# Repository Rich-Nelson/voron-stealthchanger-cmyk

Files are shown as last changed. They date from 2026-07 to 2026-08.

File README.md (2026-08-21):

# Voron Stealthchanger CMYK

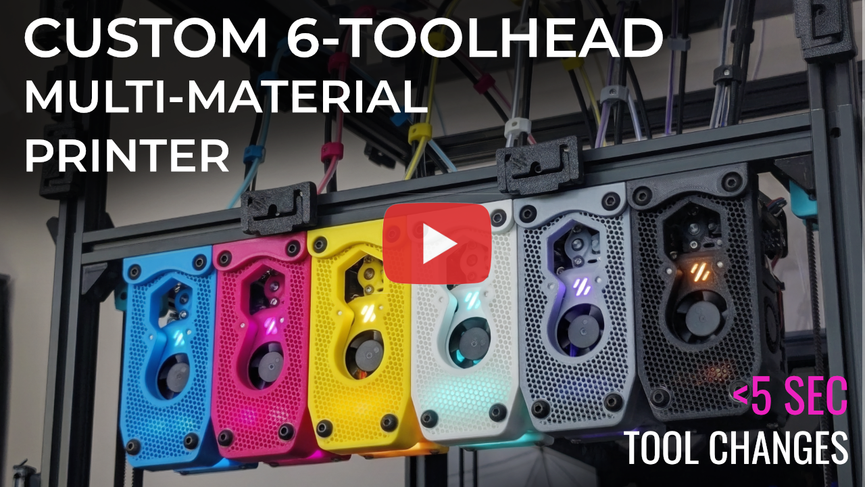
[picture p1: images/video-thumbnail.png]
Voron Stealthchanger CMYK - Watch on YouTube (https://www.youtube.com/watch?v=wOfLphvfhsM)


This repo contains all of the custom files for my 6-toolhead multi-material 3D printer, which is based on a [Voron 2.4](https://github.com/VoronDesign/Voron-2) using the [StealthChanger](https://github.com/DraftShift/StealthChanger) toolchanging system, and the [Tapchanger docking mechanism](https://github.com/viesturz/tapchanger). The build prioritizes performance, maintainability, auto calibration, and aesthetics. The CMYK in the name reffered to my printer color scheme, it's a nod to the subtractive primary colors used by 2D printers and to the capabilities of a multi tool 3D printer especially with slicer advancement like full spectrum color.

Each tool head uses a Dragon Burner toolhead with a Sharkpa Mini Extruder and TZ 2.0 V6 hotend, chosen for their combination of print quality and cost-effectiveness. The entire build is made from 3D printed parts and off-the-shelf hardware.

This repo documents all of the custom and modified components.

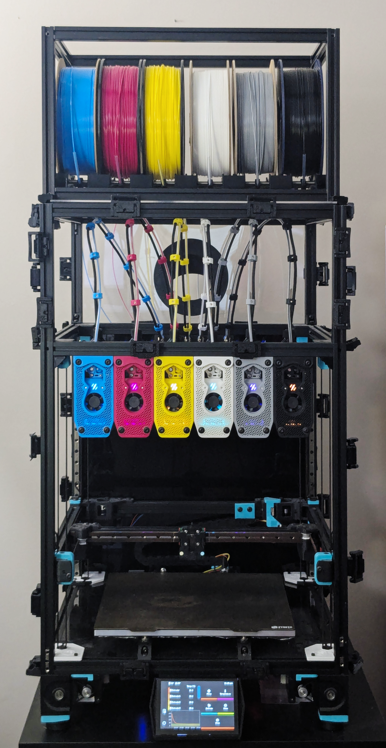
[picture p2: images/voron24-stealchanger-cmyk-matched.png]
Voron Stealthchanger CMYK


## Table of Contents

- [Filaments Used in This Build](#filaments-used-in-this-build)
- [Components](#components)
  - [Toolhead Dock](dock/)
  - [Umbilical Backplate](umbilical-backplate/)
  - [Umbilical Bracket](umbilical-bracket/)
  - [Spool Holder](spool-holder/)
  - [Dragon Burner Toolhead](dragon-burner-toolhead/)
  - [Nozzle Brush Mount](nozzle-brush-mount/)
  - [CAN Distribution Board Mount](can-distribution-board-mount/)
  - [Toolchange Tuning](toolchange-tuning/)
- [Cost Estimate Guide](COST-ESTIMATE.md)
## Filaments used in this build

Finding the right color filaments was quite difficult, since online photos do not always match the actual color. So here are the exact filaments I used so you dont't have to keep buying rolls of filament until you find the right Cyan and Magenta...

| Color | Filament | Source |
|---|---|---|
| Cyan | Polymaker ASA Pop Blue | [Amazon](https://amzn.to/4gcIvKo)
| Magenta | MatterHackers Magenta ABS | [MatterHackers](https://www.matterhackers.com/store/3d-printer-filament/magenta-abs-filament-1.75mm)
| Yellow | MatterHackers Yellow ABS | [MatterHackers](https://www.matterhackers.com/store/l/175mm-abs-filament-yellow-1-kg/sk/M-1NX-QXFR)
| White | Polymaker White ABS | [Amazon (ABS)](https://amzn.to/4cA1c8l) / [Amazon (ASA)](https://amzn.to/45FyLlC)
| Gray | Polymaker Gray ASA | [Amazon (ABS)](https://amzn.to/4xRpfb5) / [Amazon (ASA)](https://amzn.to/3ULpFkU) 
| Black | Polymaker Black ABS | [Amazon (ABS)](https://amzn.to/4zvPRzW) / [Amazon (ASA)](https://amzn.to/4xUeXqN)

---

## Components

<table>
<tr>
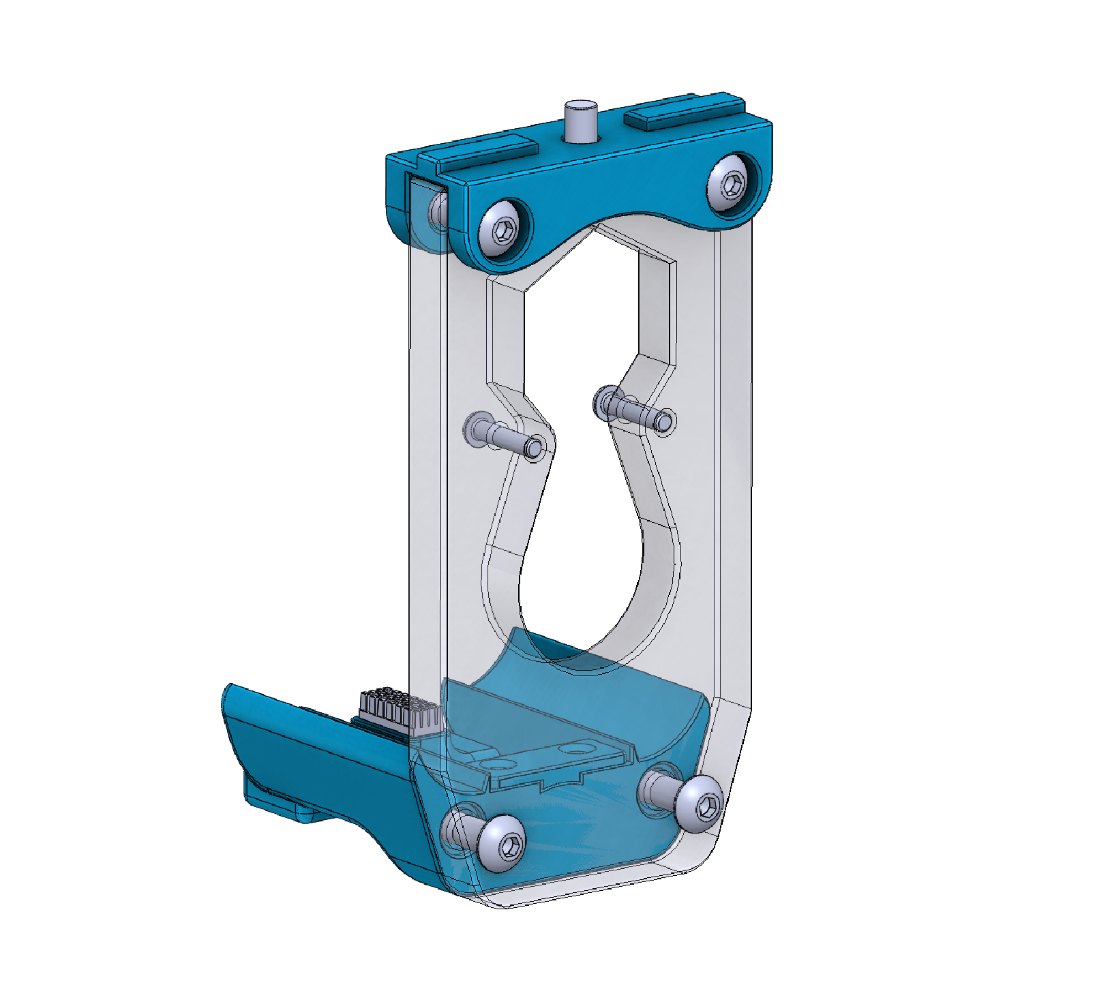
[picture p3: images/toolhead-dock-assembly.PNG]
Toolhead Dock
<td width="220"></td>
<td>

### [Toolhead Dock](dock/)
A three-part honeycomb dock, that uses the tapchanger screw hook docking mechanism. The design includes a built-in brush holder for an optional silicone nozzle wipe on every dock and undock.
</td>
</tr>
<tr>
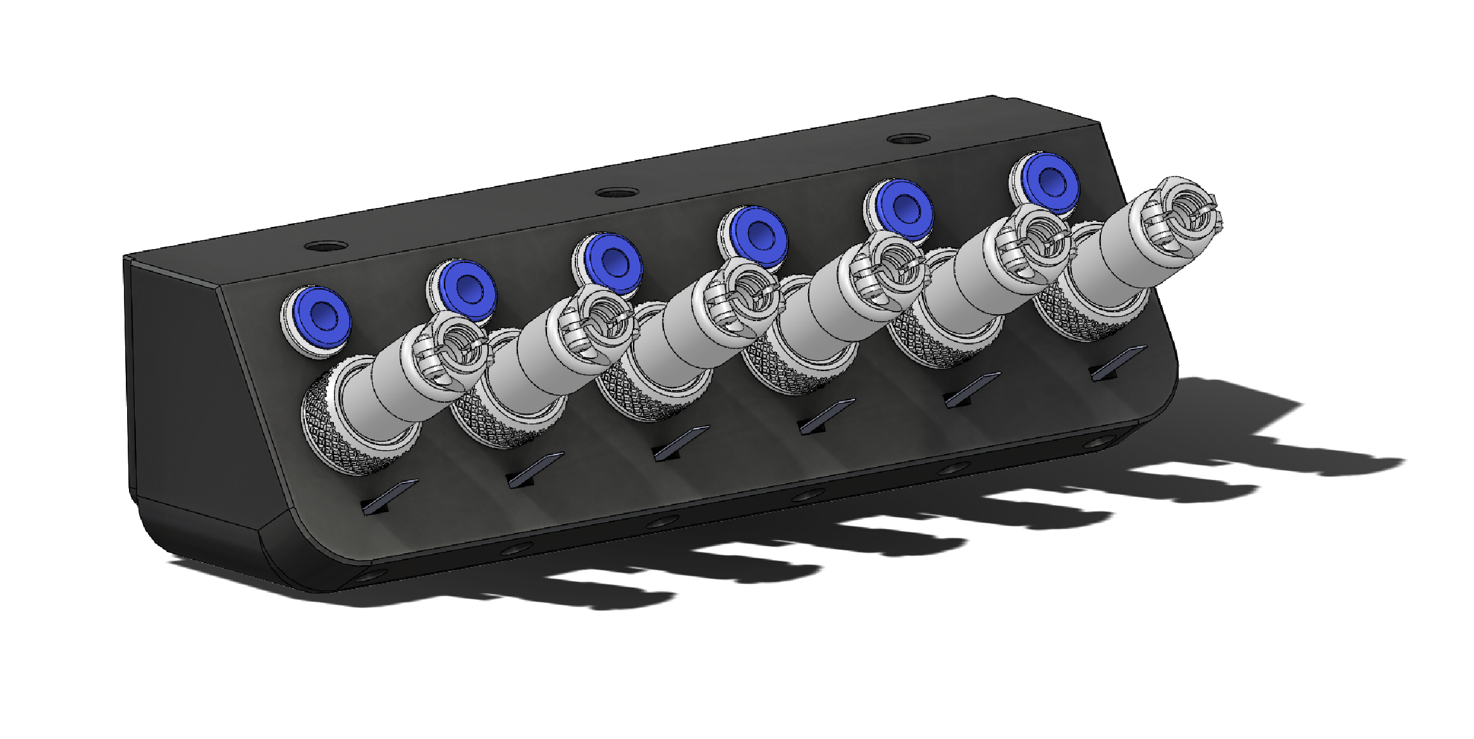
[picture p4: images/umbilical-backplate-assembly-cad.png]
Umbilical Backplate
<td width="220"></td>
<td>

### [Umbilical Backplate](umbilical-backplate/)
A backplate as the single disconnect point for all six toolhead umbilicals. CAN bus cables connect via GX12-4 jacks and filament guide tubes via ECAS04 quick-connect collets, providing a straight low-friction filament path and quick disconnect capabilities for maintenance.
</td>
</tr>
<tr>
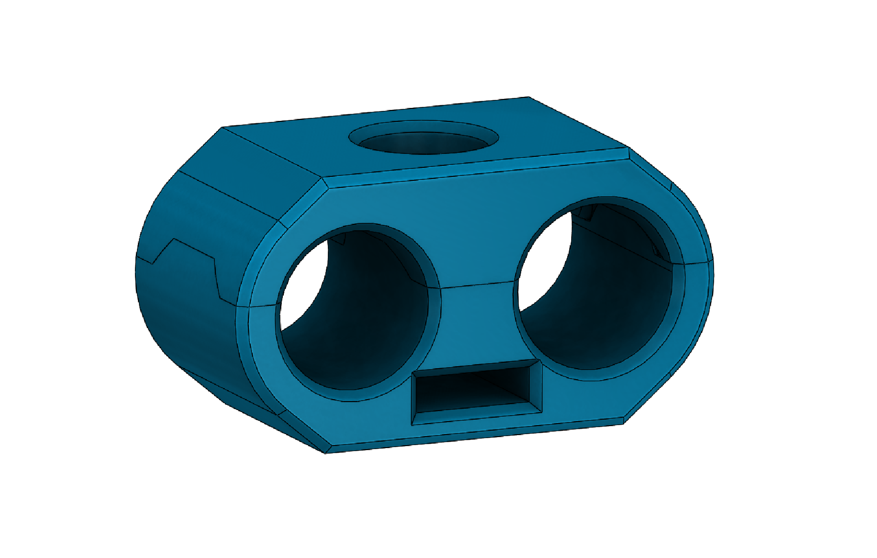
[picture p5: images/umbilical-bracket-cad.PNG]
Umbilical Bracket
<td width="220"></td>
<td>

### [Umbilical Bracket](umbilical-bracket/)
Custom brackets that bundle the CAN bus cable, PTFE filament guide tube, and flat spring steel into a flexible, organized umbilical cable assembly. The brackets clamp firmly to the cable while allowing the tube and spring steel to move freely. Spring steel is used only at the start and end of each umbilical for the ideal balance of structure and flexibility.
</td>
</tr>
<tr>
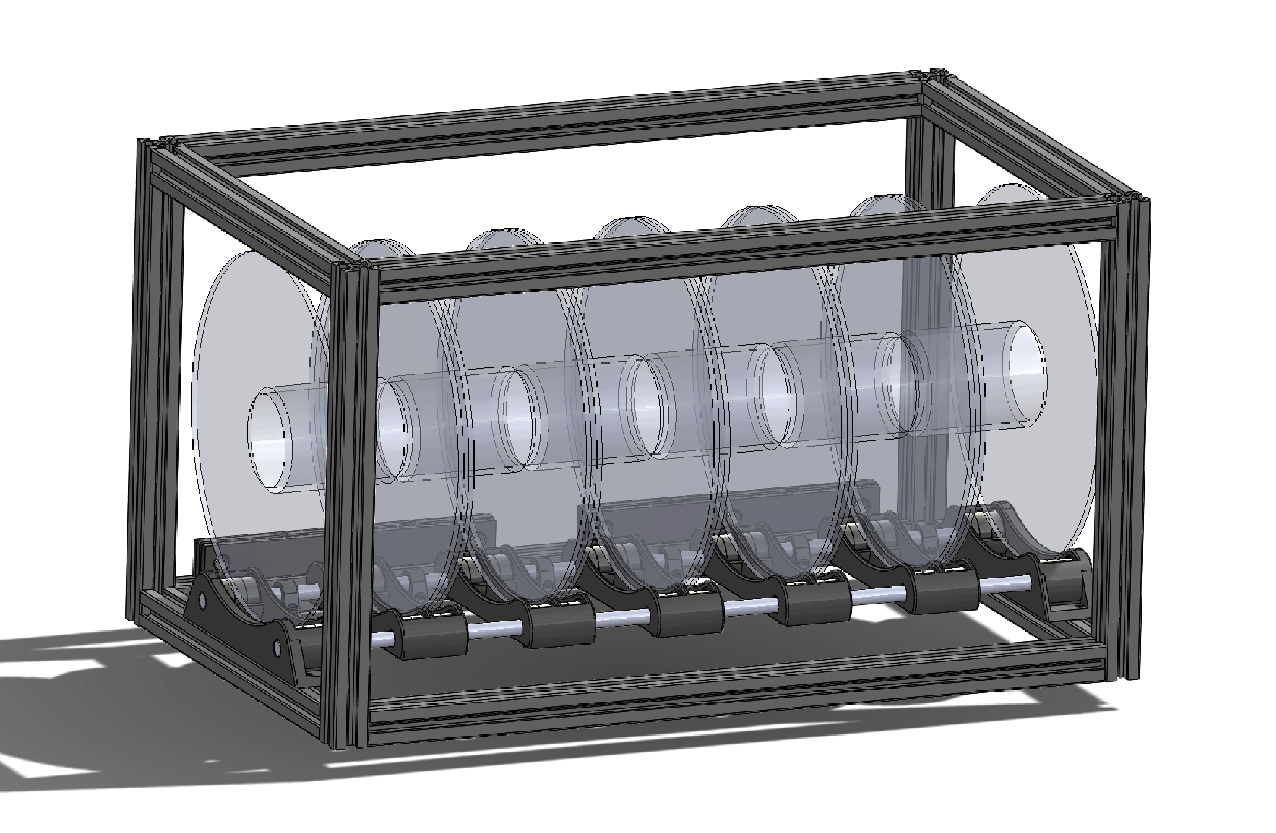
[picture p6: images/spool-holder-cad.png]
Spool Holder
<td width="220"></td>
<td>

### [Spool Holder](spool-holder/)
A compact, adjustable spool holder sized to fit within the width of the 300mm Voron 2.4 printer. Built from 2020 aluminum extrusion with roller carriages that slide along two threaded rods, accommodating different spool widths. Designed to be enclosed later and used used as a dry box.
</td>
</tr>
<tr>
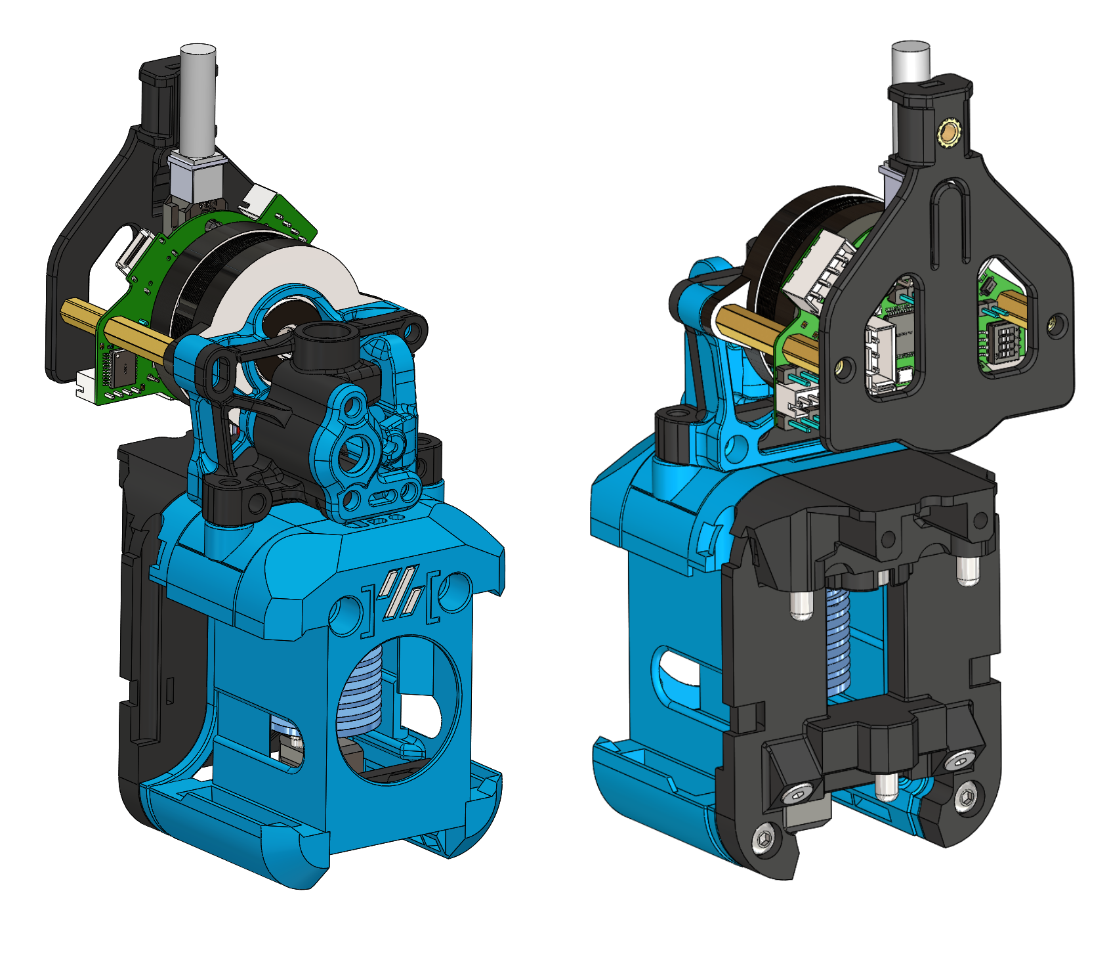
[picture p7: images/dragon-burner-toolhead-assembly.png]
Dragon Burner Toolhead
<td width="220"></td>
<td>

### [Dragon Burner Toolhead](dragon-burner-toolhead/)
A custom cowl for the [Dragon Burner](https://github.com/chirpy2605/voron/tree/main/V0/Dragon_Burner) toolhead to dock configured with a Sharkpa Mini Extruder and TZ 2.0 V6 hotend. Produces good print quality while remaining budget-friendly.
</td>
</tr>
<tr>
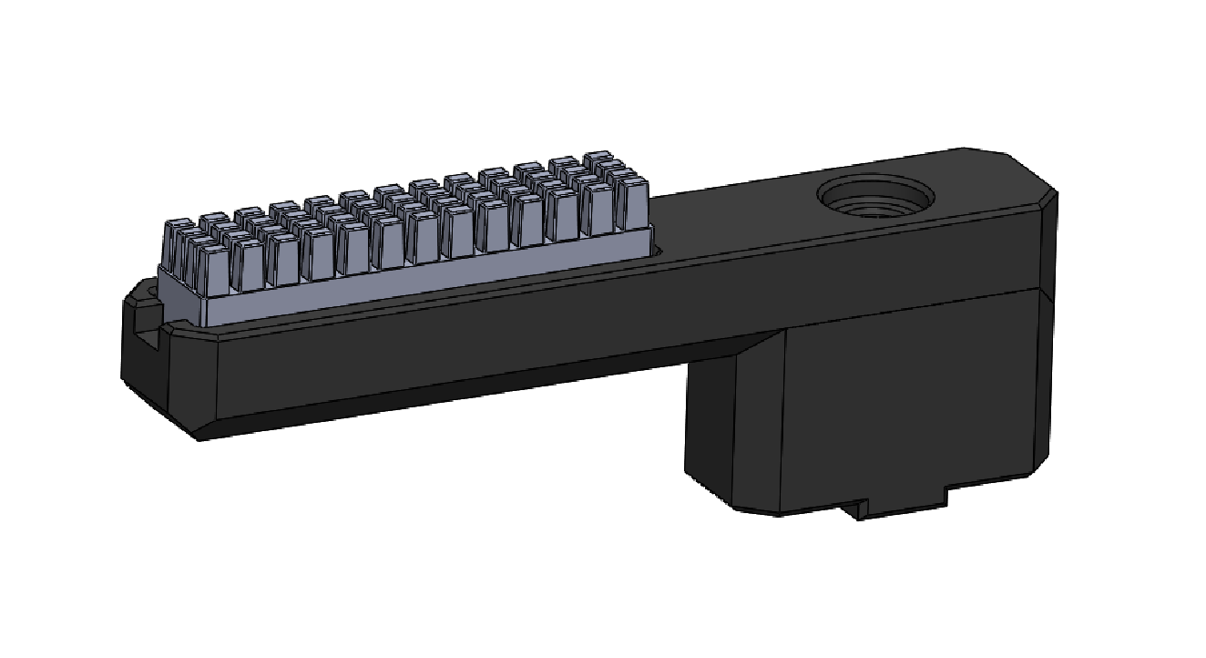
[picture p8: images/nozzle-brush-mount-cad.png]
Nozzle Brush Mount
<td width="220"></td>
<td>

### [Nozzle Brush Mount](nozzle-brush-mount/)
Mounts a silicone brush and a Sexball probe to a 2020 extrusion. The brush automatically cleans the nozzle during docking; the probe runs automatic XYZ nozzle offset calibration across all six tool heads with a single button press.
</td>
</tr>
<tr>
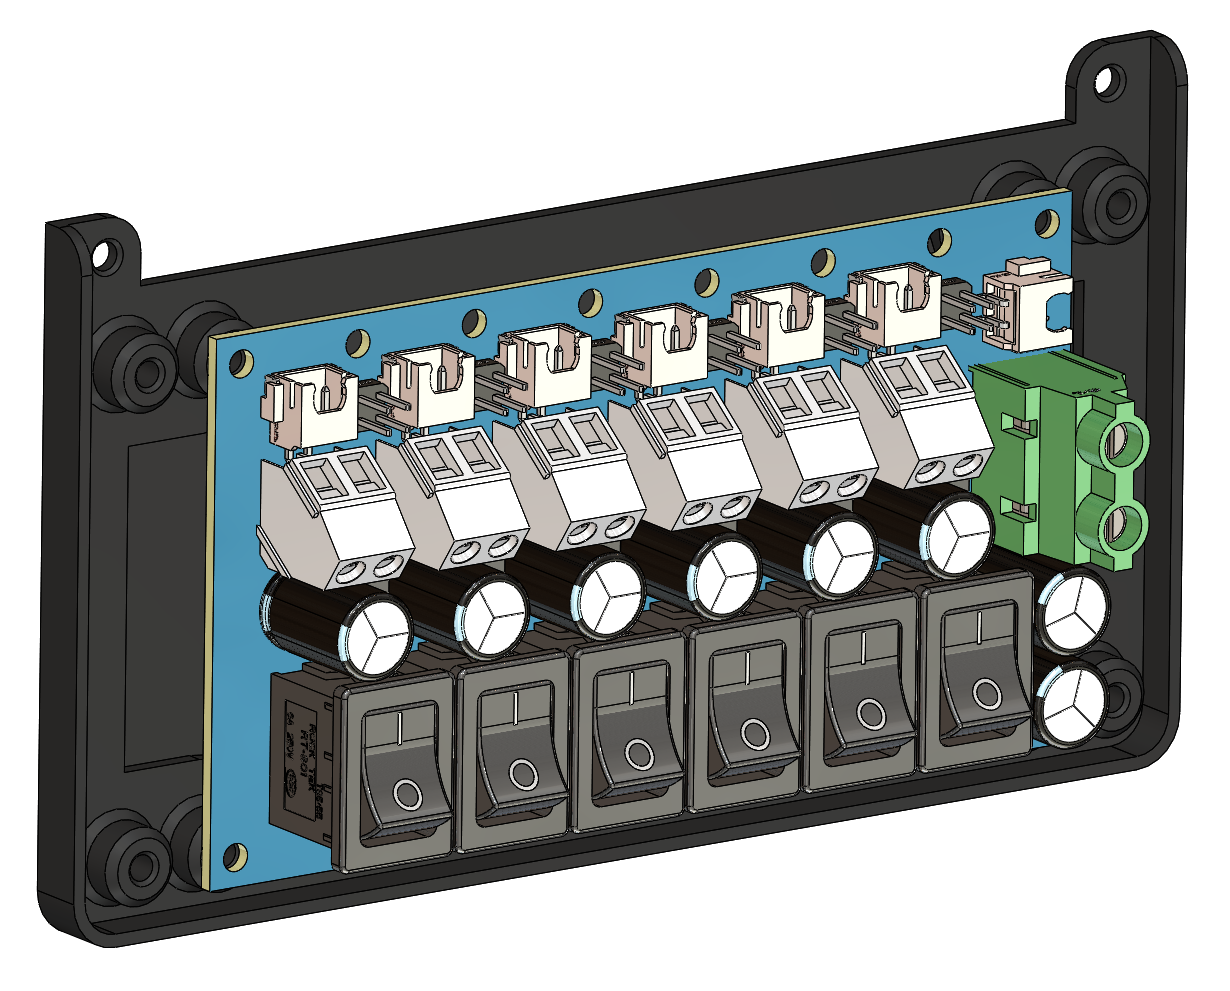
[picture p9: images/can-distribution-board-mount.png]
CAN Distribution Board Mount
<td width="220"></td>
<td>

### [CAN Distribution Board Mount](can-distribution-board-mount/)
A mount/enclosure for the FYSETC CAN Bus Distribution Board for StealthChanger, giving each of the six toolboards its own switched power channel off the shared CAN bus.
</td>
</tr>
<tr>
<td width="220" align="center">🛠️</td>
<td>

### [Toolchange Tuning](toolchange-tuning/)
Tuned motion parameters and dock path waypoints to reduce toolchange time. Covers changes to `printer.cfg` and StealthChanger macro configs, including a trimmed 4-waypoint dock path that removes the high-Z ramp-in from the default.
</td>
</tr>
</table>

---

## Cost Estimate Guide

A common question is: **"How much does this build cost?"** Full breakdown (base printer, toolchanger upgrade, per-toolhead cost, filament, and misc hardware) has moved to its own file: **[COST-ESTIMATE.md](COST-ESTIMATE.md)**.

Quick summary: **~$691** for a 6-toolhead upgrade (excl. base printer and additional filament colors), or **~$92.32** per toolhead if you're building a different count.

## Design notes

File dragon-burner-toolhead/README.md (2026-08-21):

# Dragon Burner Toolhead Cowl

Dragon Burner Cowl CAD

A custom cowl for the [Dragon Burner](https://github.com/chirpy2605/voron/tree/main/V0/Dragon_Burner) toolhead by chirpy2605. Configured with a Sharkpa Mini Extruder and TZ 2.0 V6 hotend, a combination selected after testing multiple setups for the best balance of print quality and cost.

There are also files for the EBB36 toolhead board cover that provides strain relief for the CAN Bus cable and a mounting point for the spring steel umbilical guide.

Six of these toolheads are used across the printer, each printed in its corresponding CMYK color (Cyan, Magenta, Yellow, Black, White, and Gray).

---

## Bill of Materials

### Base Toolhead

This build starts from the Dragon Burner toolhead and mounts to the printer via the StealthChanger backplate, neither of which are included in this repo:

| Part | Qty | Unit Cost | Total Cost | Source | Alt Source | Note |
|---|-----|---|---|---|---|---|
| Dragon Burner Toolhead | 1 | | | [chirpy2605/voron-user-mods](https://github.com/chirpy2605/voron-user-mods/tree/main/Universal/DragonBurner) | | Base toolhead body, printed parts, and hardware this cowl mounts to; external assembly hardware covered by overall misc hardware estimate, see main README |
| StealthChanger DragonBurner Backplate | 1 | | | [StealthChanger project](https://stealthchanger.com/hardware/guides/backplates/4_dragonburner/#printed-bom) | | Printed backplate that mounts the toolhead to the StealthChanger toolchanger |
| 4x12mm M3 Dowel Pin | 3 | $0.75 | $2.25 | [AliExpress](https://s.click.aliexpress.com/e/_c3iT67xV) | [Amazon](https://amzn.to/4gjgK1h) | Sold in packs of 10; secures the StealthChanger backplate |

### Component Selections

The Dragon Burner design supports several configurable options for hotend, extruder, motor, toolboard, and probe. These are the specific ones selected for this build.

| Part | Qty | Unit Cost | Total Cost | Source | Alt Source | Note |
|---|-----|---|---|---|---|---|
| TZ V6 2.0 Hotend | 1 | $17.87 | $17.87 | [AliExpress](https://s.click.aliexpress.com/e/_c3Mq5ohd) | [Amazon](https://amzn.to/4wB6uYB) | |
| Moons Nema14 Motor | 1 | $19.84 | $19.84 | [AliExpress](https://s.click.aliexpress.com/e/_c3PY8IAP) | [Amazon](https://amzn.to/4wGdByK) | |
| BIGTREETECH EBB36 CANBus Toolhead Board V1.2 | 1 | $15.39 | $15.39 | [AliExpress](https://s.click.aliexpress.com/e/_c3MC48Xt) | | |
| Voron Tap Probe Kit | 1 | $9.19 | $9.19 | [AliExpress](https://s.click.aliexpress.com/e/_c3SsvTCX) | [Amazon](https://amzn.to/4goA2T5) | |
| Gdstime 3010 24V Sleeve 2P2.54 Fan | 1 | $4.08 | $4.08 | [AliExpress](https://s.click.aliexpress.com/e/_c3NtUlNp) | [Amazon](https://amzn.to/4wLNCWN) | |
| Gdstime 4010 24V H Blower 2P2.54 Fan | 2 | $5.14 | $10.28 | [AliExpress](https://s.click.aliexpress.com/e/_c4E8RYo3) | [Amazon](https://amzn.to/45YBXcp) | |
| Sherpa Mini Extruder | 1 | $4.08 | $4.08 | [Annex-Engineering/Sherpa_Mini-Extruder](https://github.com/Annex-Engineering/Sherpa_Mini-Extruder) | | Self-printed; cost shown is a cheap AliExpress hardware kit ([AliExpress](https://s.click.aliexpress.com/e/_c4qK86KB) / [Amazon](https://amzn.to/3Sp1WWZ)) (bearings/pins/springs), see project for full BOM and print settings |

### Mods (This Repo)

Custom parts and hardware added on top of the base toolhead.

#### Cowl

| Part | Qty | Unit Cost | Total Cost | Source | Alt Source | Note |
|---|-----|---|---|---|---|---|
| dragonburner-cowl.STL | 1 | | | | | Printed part |
| 35mm M3 Socket Head Cap Screw | 2 | $0.23 | $2.25 | [AliExpress](https://s.click.aliexpress.com/e/_c3tmFYGL) | [Amazon](https://amzn.to/4xbUg9I) | $2.25 per 10pc pack, only sold as a full pack |

#### EBB36 Strain Relief Cover

| Part | Qty | Unit Cost | Total Cost | Source | Alt Source | Note |
|---|-----|---|---|---|---|---|
| ebb36-strain-relief-cover.STL | 1 | | | | | Printed part |
| M2 12mm Standoff (Male-Female) | 2 | | | | | Covered by overall misc hardware estimate, see main README |
| M3 18mm Standoff (Female-Female) | 2 | | | | | Covered by overall misc hardware estimate, see main README |
| M3 Heatset Insert 5mm D x 4mm L | 1 | | | | | Same insert used elsewhere in this project; covered by overall misc hardware estimate, see main README |
| M3 20mm Button Head Cap Screw | 2 | | | | | Covered by overall misc hardware estimate, see main README |
| M3 8mm Socket Head Cap Screw | 2 | | | | | Covered by overall misc hardware estimate, see main README |
| 10mm Velcro Strap or Zip Tie | 1 | | | | | Secures the strain relief connection; covered by overall misc hardware estimate, see main README |

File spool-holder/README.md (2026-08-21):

# Spool Holder

Spool Holder CAD

A compact, adjustable spool holder designed to sit on top of the printer and fit within the Voron 2.4 30mm's 460mm (18in) width. The frame is built from 2020 aluminum extrusion (matching the printer) with two threaded rods running the length. Roller carriages slide along the rods and can be repositioned to accommodate different spool widths.

Each spool rolls freely on 608 bearings for low-friction feeding. Built-in filament tube guides and quick-release ports route each filament toward the tool heads. The structure is designed to accept enclosure panels later, allowing it to double as a dry box with desiccant or a dehumidifier.

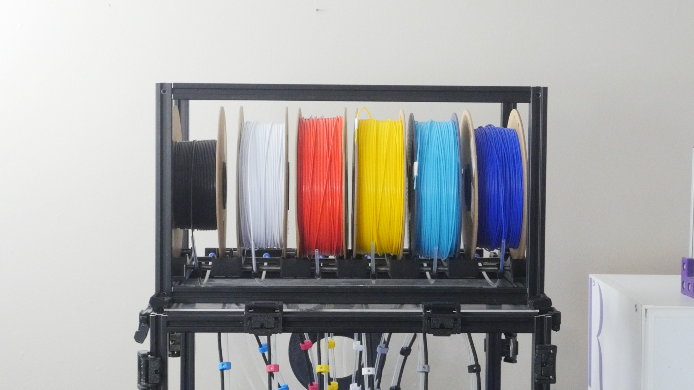
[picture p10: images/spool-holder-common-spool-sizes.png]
Common Spool Sizes


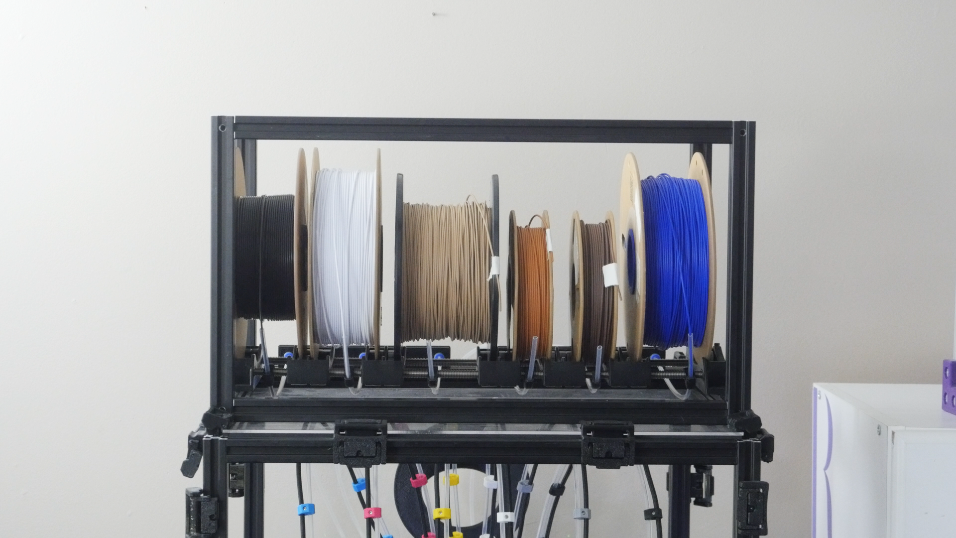
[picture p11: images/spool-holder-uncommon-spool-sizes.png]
Uncommon Spool Sizes


---

## Bill of Materials

### Printed Parts

| Part | Qty |
|---|-----|
| spool-holder-roller-end.STL | 2 |
| spool-holder-roller-divider.STL | 5 |
| spool-holder-tube-guide.STL | 6 |
| spool-holder-port.STL | 2 |

### Hardware

| Part | Qty | Unit Cost | Total Cost | Source | Alt Source | Note |
|---|-----|---|---|---|---|---|
| 2020 Extrusion, 420mm Length | 4 | | $49.99 | [Amazon](https://amzn.to/4hoHVKv) | [Amazon (alt)](https://amzn.to/4gHHdXQ) | Cut from a 10pc pack of 500mm bars, only sold as a full pack |
| 2020 Extrusion, 260mm Length | 4 | | | [Amazon](https://amzn.to/4hoHVKv) | [Amazon (alt)](https://amzn.to/4gHHdXQ) | Cut from the same pack (pairs with a 240mm piece per bar), cost counted on the 420mm line |
| 2020 Extrusion, 240mm Length | 4 | | | [Amazon](https://amzn.to/4hoHVKv) | [Amazon (alt)](https://amzn.to/4gHHdXQ) | Cut from the same pack (pairs with a 260mm piece per bar), cost counted on the 420mm line |
| 8mm x 460mm Rod (Smooth or Threaded) | 2 | $5.10 | $10.10 | [AliExpress](https://s.click.aliexpress.com/e/_c4NcuZcf) | [Amazon](https://amzn.to/4g3PELE) | Sourced as 2pc pack of 8mm x 500mm linear rod, cut to length |
| 608 Bearings (base) | 4 | $0.27 | $1.07 | [Amazon](https://amzn.to/4cwubtG) | [AliExpress](https://s.click.aliexpress.com/e/_c3qePSft) | $5.36 per 20-pack, not tied to a toolhead |
| 608 Bearings (per toolhead x6) | 48 | $0.27 | $12.86 | [Amazon](https://amzn.to/4cwubtG) | [AliExpress](https://s.click.aliexpress.com/e/_c3qePSft) | $5.36 per 20-pack, 8 per toolhead |
| ECAS04 Quick Connect Collet | 12 | $0.25 | $3.00 | [AliExpress](https://www.aliexpress.us/item/3256812555226121.html) | [Amazon](https://amzn.to/4gs7Q1K) | 2 per toolhead x6 |
| PTFE Tube Clear, 4mm OD x 3mm ID (~26in) | 6 | $1.27 | $7.63 | [AliExpress](https://s.click.aliexpress.com/e/_c3qePSft) | [Amazon](https://amzn.to/4gMqQIz) | $1.93/meter, spool holder to umbilical plate, 1 per toolhead |
| PTFE Tube Clear, 4mm OD x 3mm ID (~10in) | 6 | $0.49 | $2.94 | [AliExpress](https://s.click.aliexpress.com/e/_c3qePSft) | [Amazon](https://amzn.to/4gMqQIz) | $1.93/meter, internal guide, 1 per toolhead |
| M5 10mm Button Head Cap Screw | 16 | | | [Amazon](https://amzn.to/4hoHVKv) | | Covered by overall misc hardware estimate, see main README |
| M3 Heatset Insert 5mm D x 4mm L | 4 | | | | | Covered by overall misc hardware estimate, see main README |
| M3 12mm Socket Head Cap Screw | 4 | | | | | Covered by overall misc hardware estimate, see main README |
| M3 10mm Socket Head Cap Screw | 4 | | | | | Covered by overall misc hardware estimate, see main README |
| M3 2020 Roll Nut | 4 | | | | | Covered by overall misc hardware estimate, see main README |

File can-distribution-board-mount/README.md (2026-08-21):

# CAN Distribution Board Mount

CAN Distribution Board Mount CAD

A mount/enclosure for the FYSETC CAN Bus Distribution Board for StealthChanger, which splits the CAN bus and switched power out to each of the six toolboards. Each channel has its own rocker switch, letting individual toolheads be powered off independently for maintenance or troubleshooting without shutting down the whole bus.

---

## Bill of Materials

### Printed Parts

| Part | Qty | Note |
|---|-----|---|
| can-distribution-board-mount.STL | 1 | |

### Hardware

| Part | Qty | Unit Cost | Total Cost | Source | Note |
|---|-----|---|---|---|---|
| FYSETC CAN Bus Distribution Board for StealthChanger | 1 | $19.99 | $19.99 | [Fabreeko](https://www.fabreeko.com/products/can-bus-distribution-board-for-stealth-changer-by-fysetc) | 6-channel switched CAN/power distribution |
| M3 8mm Thread Rolling Screw | 4 | | | | Mounts the distribution board to the mount; covered by overall misc hardware estimate, see main README |
| M3 10mm Socket Head Cap Screw | 2 | | | | Attaches the mount to the Umbilical Backplate; covered by overall misc hardware estimate, see main README |

### Suggested Pairing

Not part of this mount, but a common companion since it needs to connect somewhere upstream on the CAN bus:

| Part | Qty | Unit Cost | Total Cost | Source | Alt Source | Note |
|---|-----|---|---|---|---|---|
| BTT U2C CAN Bridge | 1 | $19.99 | $19.99 | [Amazon](https://amzn.to/45Fp9Hz) | [AliExpress](https://s.click.aliexpress.com/e/_c3FzcP0n) | Host-side USB-to-CAN adapter |

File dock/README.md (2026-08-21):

# Toolhead Dock

Toolhead Dock Assembly

A three-part dock designed for the StealthChanger system. The docking mechanism hooks the toolhead onto two screw heads, a tap-changer style approach that has proven extremely reliable with zero tool change failures during printing.

The dock was originally designd to use a 10mm acrylic panel as the plate, but it can be printed as well, leavnig the infill exposed lets you see through to the toohead and it doubles as an LED light diffuser. An optional brush holder on the bottom of the dock accepts a silicone nozzle brush so the nozzle is automatically wiped on every dock and undock cycle.

> Printing note: for the honey comb effect on the toolhead-dock-plate.STL Print with the fllowing settings:
>- 0 top/bottom layers
>- 8 perimeters
>- 25% density honeycomb infill

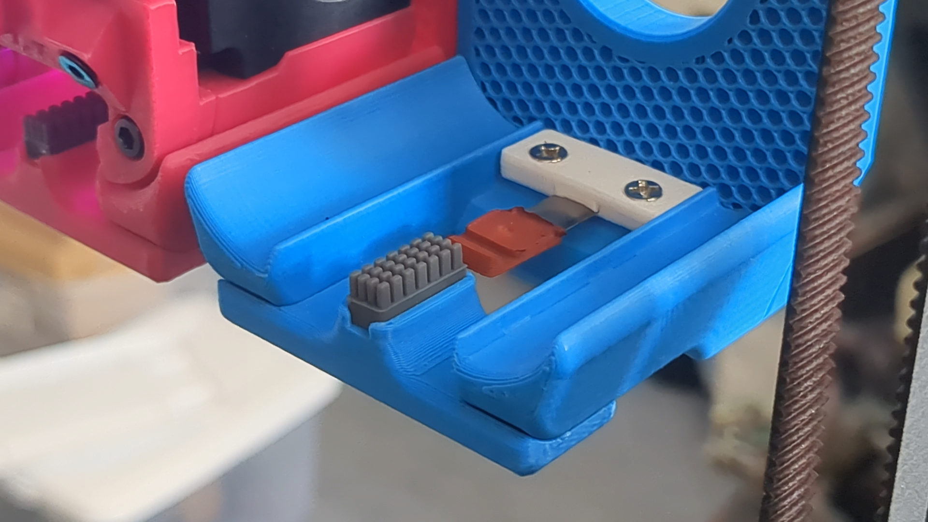
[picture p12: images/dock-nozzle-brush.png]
Nozzle Brush on Dock


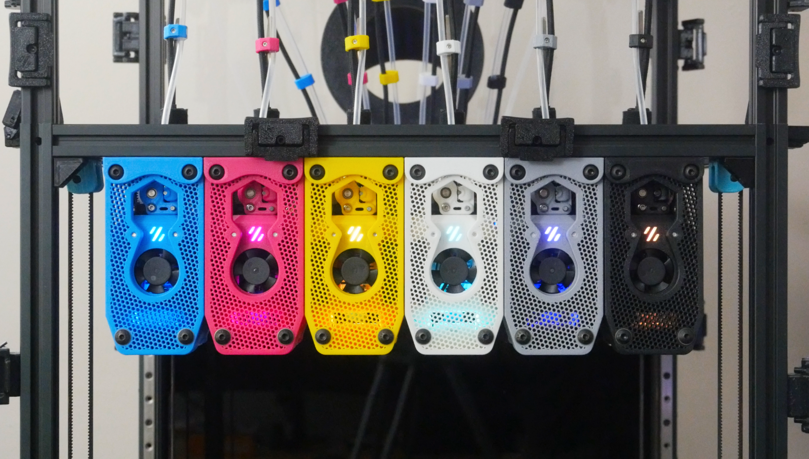
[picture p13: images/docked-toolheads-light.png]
Docked Toolheads


---

## Bill of Materials

### Printed Parts

| Part | Qty |
|---|-----|
| toolhead-dock-base.STL | 1 |
| toolhead-dock-plate.STL | 1 |
| toolhead-dock-bracket.STL | 1 |
| toolhead-dock-brush-holder.STL | 1 |
| toolhead-dock-nozzle-pad-clip.STL | 1 |

### Hardware

| Part | Qty | Unit Cost | Total Cost | Source | Alt Source | Note |
|---|-----|---|---|---|---|---|
| Silicone Nozzle Brush (Bambu Lab A1 Mini size, cut in half) | 1 | $0.15 | $0.15 | [AliExpress](https://s.click.aliexpress.com/e/_c2wvhLBd) | [Amazon](https://amzn.to/4zvQkCc) | Same brush type as [Nozzle Brush Mount](../nozzle-brush-mount/), cut in half; $2.96 per 10pcs, enough for the whole build + extras |
| M5 Heatset Insert 7mm D x 5mm L | 4 | | | | | Covered by overall misc hardware estimate, see main README |
| M3 Heatset Insert 5mm D x 4mm L | 2 | | | | | Covered by overall misc hardware estimate, see main README |
| 16mm M5 Button Head Cap Screw | 4 | | | | | Covered by overall misc hardware estimate, see main README |
| 10mm M5 Button Head Cap Screw | 1 | | | | | Covered by overall misc hardware estimate, see main README |
| 14mm M3 Button Head Cap Screw | 2 | | | | | Covered by overall misc hardware estimate, see main README |
| 8mm M3 Button Head Cap Screw | 2 | | | | | Covered by overall misc hardware estimate, see main README |

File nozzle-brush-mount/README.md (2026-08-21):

# Nozzle Brush Mount

Nozzle Brush Mount CAD

A two-piece mount that attaches to the 2020 extrusion frame and holds a silicone nozzle brush and a Sexball probe in line with the docking pathway.

**Nozzle brush:** The silicone brush cleans the nozzle automatically before a print, and before nozle offset calibration, preventing plastic buildup that could otherwise affect print quality or calibration accuracy.

**Sexball probe:** The the probe used to measure the nozzle position from multiple angles. XYZ offsets are then applied automatically across all six tool heads, eliminating the need for manual calibration. You can find details here: [Sexball BOM](https://github.com/DraftShift/StealthChanger/wiki/Bill-of-Materials#sexball-probe)

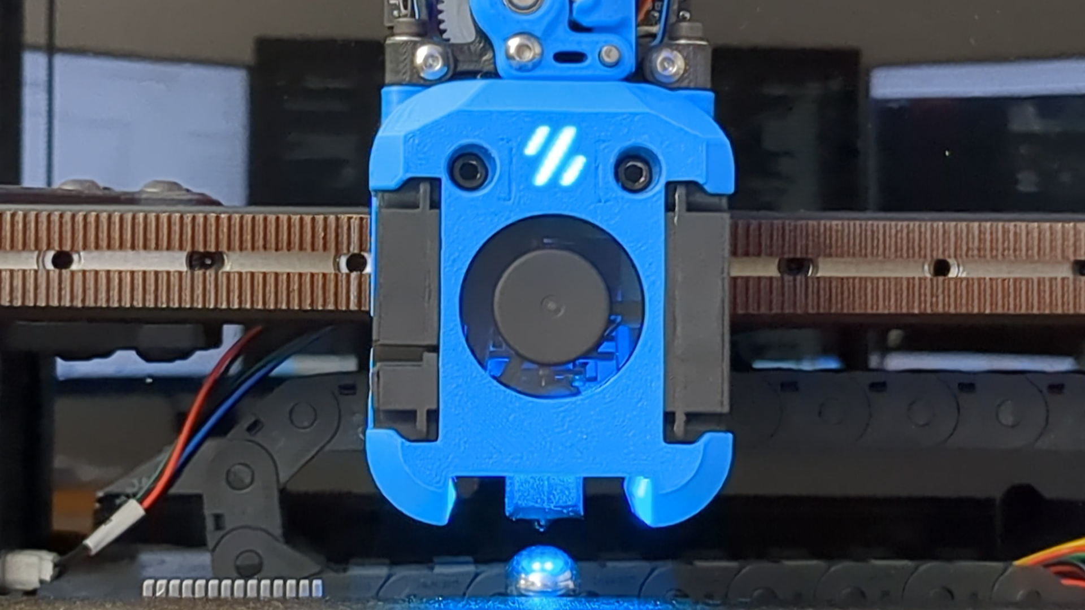
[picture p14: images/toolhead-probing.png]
Toolhead Probing


---

## Bill of Materials

### Printed Parts

| Part | Qty |
|---|-----|
| nozzle-brush-mount-base.STL | 1 |
| nozzle-brush-mount-top.STL | 1 |

### Hardware

| Part | Qty | Unit Cost | Total Cost | Note |
|---|-----|---|---|---|
| Silicone Nozzle Brush (for Bambu Lab A1/A1 MINI) | 1 | | | Covered by overall misc hardware estimate, see main README |
| 20mm M3 Socket Head Cap Screw | 1 | | | Covered by overall misc hardware estimate, see main README |
| M3 2020 Roll Nut | 1 | | | Covered by overall misc hardware estimate, see main README |

### Related Projects

The Sexball probe is mounted by this bracket but is not part of this repo:

| Part | Source | Note |
|---|---|---|
| Sexball Probe Assembly | [Sexball BOM](https://github.com/DraftShift/StealthChanger/wiki/Bill-of-Materials#sexball-probe) | See project for parts and sourcing |

#### Sexball Probe Parts (as sourced for this build)

| Part | Qty | Unit Cost | Total Cost | Source | Alt Source | Note |
|---|-----|---|---|---|---|---|
| Mellow Hartk Sexbolt Z Limit Endstop | 1 | $10.90 | $10.90 | [AliExpress](https://s.click.aliexpress.com/e/_c2vVlF4R) | [Amazon](https://amzn.to/4bZMur3) | |
| M5 30mm Stainless Steel Outside Thread Solid Dowel Pin | 5 | $0.63 | $3.14 | [AliExpress](https://s.click.aliexpress.com/e/_c3g0o8ox) | [Amazon](https://amzn.to/4zzrLEI) | Pack of 5 |
| 12.7 or 12mm D M5 Stainless Steel Drilling Balls, Female Thread | 1 | $6.64 | $6.64 | [AliExpress](https://s.click.aliexpress.com/e/_c2wXXZR9) | [Amazon](https://amzn.to/46cNQv5) | |

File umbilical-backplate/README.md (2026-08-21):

# Umbilical Backplate

Umbilical Backplate Assembly CAD

A wall-mounted plate that acts as the single connection point where all six toolhead umbilicals enter the printer from the back. The design was driven by ease of maintenance: all connections can be quickly detached for cable troubleshooting, filament tube swaps, or toolhead work without disassembling the printer.

**CAN bus cables** connect via GX12-4 four-pin jacks. **Filament guide tubes** use ECAS04 press-fit quick-connect collets, which allow a straight, low-friction filament path while keeping a low profile to maintain clearance for the wiring below. The plate mounts directly to the printer's 2020 extrusion frame.

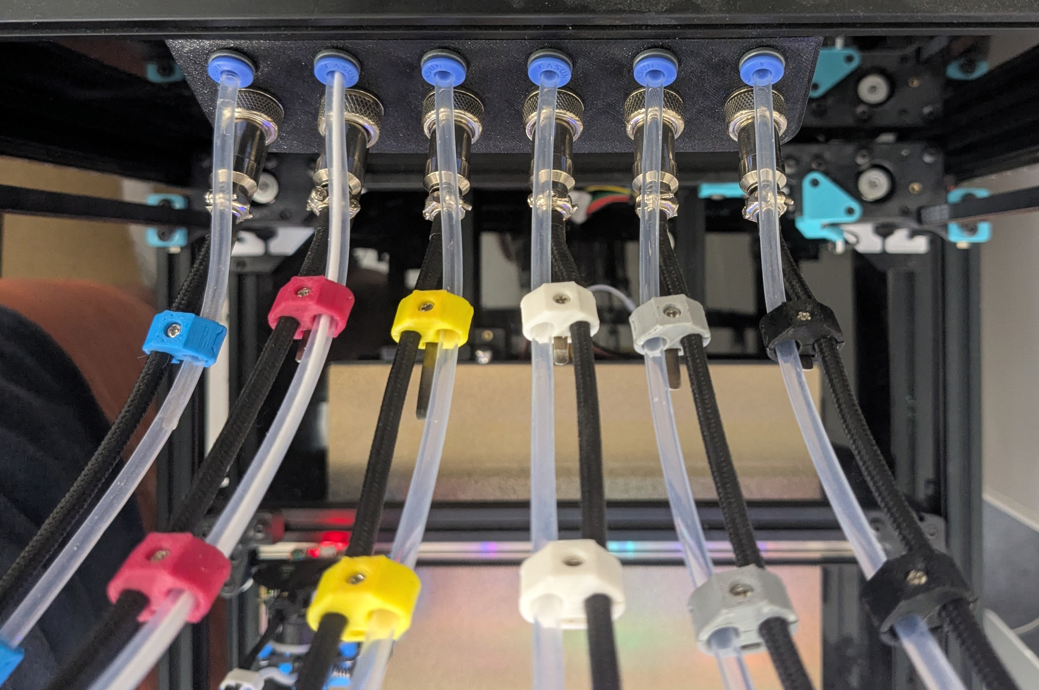
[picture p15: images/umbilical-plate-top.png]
Umbilical Plate Top View


---

## Bill of Materials

### Printed Parts

| Part | Qty |
|---|-----|
| umbilical-backplate.STL | 1 |
| umbilical-backplate-nut-retainer.STL | 1 |

### Hardware

| Part | Qty | Unit Cost | Total Cost | Source | Alt Source | Note |
|---|-----|---|---|---|---|---|
| ECAS04 Quick Connect Collet | 12 | $0.25 | $3.00 | [AliExpress](https://www.aliexpress.us/item/3256812555226121.html) | [Amazon](https://amzn.to/4gs7Q1K) | |
| GX12-4 Jack | 6 | $0.59 | $3.54 | [AliExpress](https://s.click.aliexpress.com/e/_c2vhMl6x) | [Amazon](https://amzn.to/4gaFnOZ) | Price per male/female pair (includes mating GX12-4 Plug), 1 pair per toolhead |
| M3 Heatset Insert 5mm D x 4mm L | 6 | | | | | Covered by overall misc hardware estimate, see main README |
| M3 x 10mm Screw or M3 Set Screw | 6 | | | | | Covered by overall misc hardware estimate, see main README |
| M5 10mm Button Head Cap Screw | 3 | | | | | Covered by overall misc hardware estimate, see main README |
| M5 2020 Roll Nut | 3 | | | | | Covered by overall misc hardware estimate, see main README |

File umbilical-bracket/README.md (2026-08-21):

# Umbilical Bracket

Umbilical Bracket CAD

A custom two-piece clamp bracket that bundles the three elements of each toolhead umbilical (a CAN bus cable, a PTFE filament guide tube, and flat spring steel) into a single organized assembly.

The bracket clamps firmly onto the CAN bus cable to maintain consistent spacing and orientation along the umbilical, while leaving enough room for the PTFE tube and spring steel to move freely. This gives the umbilical enough structure to stay organized without becoming too stiff to reach all areas of the print bed.

Flat spring steel is used only at the start and end of each umbilical rather than the full length, which proved to be the best balance between structure and flexibility. Eight umbilical assemblies are used in total, one per toolhead (six active + two spare).

Umbilical Brackets Assembled

---

## Bill of Materials

### Bracket: Printed Parts

| Part | Qty |
|---|-----|
| umbilical-bracket-bottom.STL | 1 |
| umbilical-bracket-top.STL | 1 |

### Bracket: Hardware

| Part | Qty | Unit Cost | Total Cost | Note |
|---|-----|---|---|---|
| M3 Thread Rolling Screw | 1 | | | Covered by overall misc hardware estimate, see main README |

---

### Full Umbilical Assembly
*Per umbilical, 8 total (one per toolhead)*

| Part | Qty | Unit Cost | Total Cost | Source | Alt Source | Note |
|---|-----|---|---|---|---|---|
| Umbilical bracket (assembled) | 8 | | | | | See Bracket Hardware above |
| CAN Bus Cable, 4mm diameter (~23.5 in / 600mm) | 1 | $4.00 | $4.00 | | | Cut from a 6ft 100W shielded USB-C cable (2 CAN cables per 6ft USB-C cable); the exact cable I used is no longer sold. **Verify your replacement cable's rating meets your toolhead electronics' requirements** - alternatives include a 240W USB-C cable or a chainflex cable |
| PTFE Guide Tube, 4mm OD x 3mm ID (~26 in / 660mm) | 1 | $1.27 | $1.27 | [AliExpress](https://s.click.aliexpress.com/e/_c3qePSft) | [Amazon](https://amzn.to/4gMqQIz) | $1.93/meter |
| GX12-4 Plug | 1 | | | [AliExpress](https://s.click.aliexpress.com/e/_c2vhMl6x) | [Amazon](https://amzn.to/4gaFnOZ) | Priced with the mating GX12-4 Jack, see [Umbilical Backplate](../umbilical-backplate/) BOM |
| 2x2 Microfit Connector | 1 | | | [Amazon](https://amzn.to/4ifp2tK) | | Comes with the EBB36 toolboard, not purchased separately |
| Flat Coil Spring, 0.3mm x 3mm (70mm length) | 1 | $1.67 | $13.39 | [Amazon](https://amzn.to/4wyCufH) | [AliExpress](https://s.click.aliexpress.com/e/_c2xB7uAf) | Cut from a 0.3x3x34x1900mm roll ($11.00 total, ~$1.67/umbilical); one roll covers the whole build (8 umbilicals) |
| Flat Coil Spring, 0.3mm x 3mm (100mm length) | 1 | | | [Amazon](https://amzn.to/4wyCufH) | [AliExpress](https://s.click.aliexpress.com/e/_c2xB7uAf) | Cut from the same roll, cost counted on the 70mm line |

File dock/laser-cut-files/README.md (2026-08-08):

# Laser Cut Files for Stealthchanger Dock

These DXF files are for laser cutting the toolhead dock plates for the Stealthchanger, as an alternative to printing toolhead-dock-plate.STL.

## Important Note on Material Thickness

The barckets that hole these plate (toolhead-dock-bracket.STL) were designed specifically for 10mm acrylic that had an actual measured thickness of **9.5mm**.

If you are using a different thickness of acrylic (or other material), the dock bracket will need to be adjusted accordingly to ensure a proper fit.

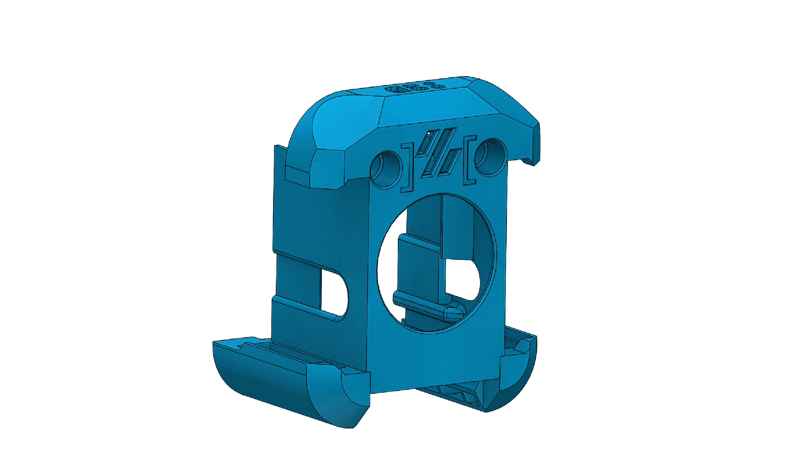
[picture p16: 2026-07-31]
images/dragonburner-cowl-cad.png

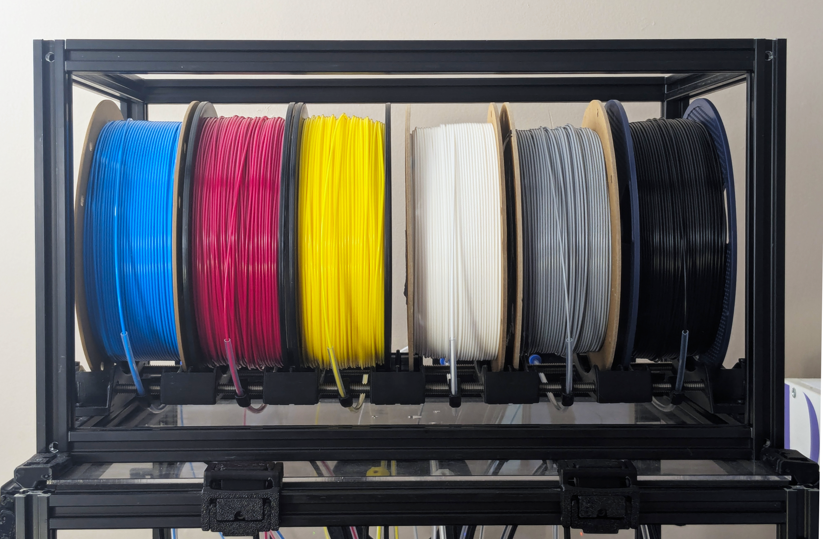
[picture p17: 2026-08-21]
images/spool-holder-cmyk.png

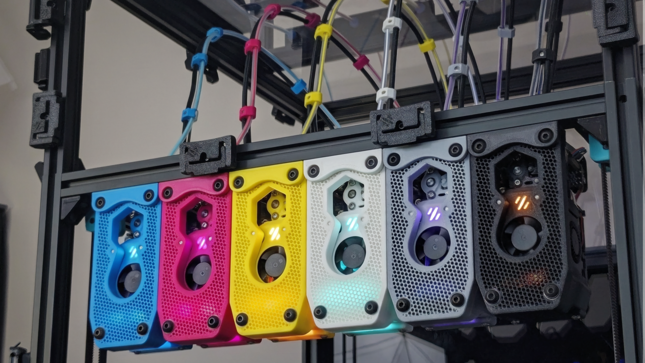
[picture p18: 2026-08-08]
images/voron-stealthchanger-cmyk-angled-view.png

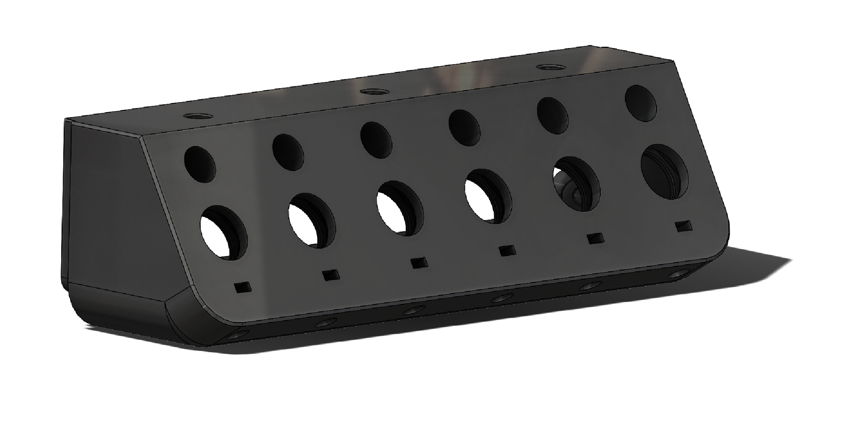
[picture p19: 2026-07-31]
images/umbilical-backplate-cad.png

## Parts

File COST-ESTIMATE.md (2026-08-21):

# Cost Estimate Guide

A common question is: **"How much does this build cost?"** It's hard to give one number since it depends heavily on your base printer and which components you choose, so the estimate below is broken into three buckets. Prices marked `~` are rough estimates (either an online price I haven't personally paid, or a ballpark for small hardware I didn't individually source/track) - everything else links to what I actually bought.

> Most purchase links in this guide (AliExpress, Amazon) are affiliate links - using them may earn me a small commission at no extra cost to you.

### Summary

| Bucket | Est. Cost | Details |
|---|---|---|
| Base Printer | Varies ($839.10+ for a 300mm kit) | [Section 1](#1-base-printer) |
| Base Toolchanger Upgrade (one-time) | ~$67.20 | [Section 2](#2-base-toolchanger-upgrade-one-time) |
| 6-Toolhead Cost (each ~$92.32 ×6 for this build) | ~$553.92 | [Section 3](#3-per-toolhead-cost) |
| Misc Hardware | ~$50 | [Section 5](#5-filament--miscellaneous-hardware) |
| Filament, single color | ~$20 | [Section 5](#5-filament--miscellaneous-hardware) |
| **Estimated total (for a 6-toolhead upgrade, excl. base printer cost and additional filament colors)** | **~$691** | |
| + Spool Holder (optional add-on, not in total above) | +$87.59 | [Section 4](#4-additional-components) |

If you're building a different number of toolheads, swap in `Per-Toolhead Cost (each)` × your count instead of the ×6 row.

### 1. Base Printer

The cost of your [Voron 2.4](https://github.com/VoronDesign/Voron-2) (or similar) kit/scratch-build and any fundamental upgrades needed to get it running. This varies too widely by vendor/region to estimate here, but as a reference point, recently the best price I've found for a 300mm kit is the Formbot kit at $839.10: [AliExpress](https://www.aliexpress.us/item/3256807677153373.html).

### 2. Base Toolchanger Upgrade (one-time)

Shared components needed to convert the printer to multi-toolhead, regardless of toolhead count.

| Item | Est. Total Cost | Source | Alt Source | Note |
|---|---|---|---|---|
| BTT U2C CAN Bridge | $19.99 | [Amazon](https://amzn.to/45Fp9Hz) | [AliExpress](https://s.click.aliexpress.com/e/_c3FzcP0n) | Host-side USB-to-CAN adapter |
| FYSETC CAN Bus Distribution Board for StealthChanger | $19.99 | [Fabreeko](https://www.fabreeko.com/products/can-bus-distribution-board-for-stealth-changer-by-fysetc) | | Splits CAN bus to each toolboard, see [CAN Distribution Board Mount](can-distribution-board-mount/) |
| [Umbilical Backplate](umbilical-backplate/) hardware | $6.54 | | | ECAS04 + GX12-4 Jack; remaining screws/heatsets covered by the misc hardware estimate in section 5 |
| [Nozzle Brush Mount](nozzle-brush-mount/) hardware | | | | Brush + screw + nut covered by the misc hardware estimate in section 5 |
| Sexball Probe Assembly | $20.68 | [Sexball BOM](https://github.com/DraftShift/StealthChanger/wiki/Bill-of-Materials#sexball-probe) | | External project; endstop + dowel pins + probe balls priced, see [Nozzle Brush Mount](nozzle-brush-mount/) BOM |

**Known subtotal: ~$67.20**

### 3. Per-Toolhead Cost

The cost of one fully functional toolhead, including its dock and umbilical. Multiply by the number of tools you plan to run (this build uses 6).

| Item | Est. Total Cost | Note |
|---|---|---|
| [Dragon Burner Toolhead](dragon-burner-toolhead/) component selections (hotend, motor, toolboard, probe kit, fans, extruder hardware) | $80.73 | See component BOM for source links |
| [Dragon Burner Toolhead](dragon-burner-toolhead/) backplate mounting hardware | $2.25 | 3x 4x12mm M3 dowel pins |
| [Dragon Burner Toolhead](dragon-burner-toolhead/) cowl mod hardware | $2.25 | 35mm M3 SHCS |
| [Dragon Burner Toolhead](dragon-burner-toolhead/) EBB36 strain relief cover hardware | | Standoffs, heatset, screws, velcro covered by the misc hardware estimate in section 5 |
| [Toolhead Dock](dock/) hardware | $0.15 | Nozzle brush; heatsets/screws covered by the misc hardware estimate in section 5 |
| [Umbilical Bracket](umbilical-bracket/) + umbilical assembly | $6.94 | PTFE guide tube $1.27 + spring steel roll ~$1.67/umbilical ($13.39 roll covers all 8) + CAN cable ~$4.00 (cut from a 6ft 100W shielded USB-C cable, exact cable no longer sold - verify your replacement's rating meets your toolhead electronics' requirements; alternatives: 240W USB-C or chainflex cable); microfit connector comes with the EBB36 board; bracket screw covered by the misc hardware estimate in section 5 |

**Known subtotal per toolhead: ~$92.32**, plus filament and misc hardware (see section 5).
**Known 6-toolhead total: ~$553.92**, plus filament and misc hardware (see section 5).

### 4. Additional Components

Optional add-ons, priced separately since not every build needs them.

| Item | Est. Total Cost | Note |
|---|---|---|
| [Spool Holder](spool-holder/) | $87.59 | Bearings, ECAS04, PTFE tube, extrusion, and rod priced; remaining screws/heatsets covered by the misc hardware estimate in section 5 |

### 5. Filament & Miscellaneous Hardware

**Misc hardware estimate: ~$50** for everything not individually sourced above - these are cheap items bought in bulk, not worth tracking per-part. Covers: M3/M5 heatset inserts, various button/socket head cap screws and 2020 roll nuts (dock, spool holder, umbilical backplate/bracket, dragon burner EBB36 cover, CAN distribution mount), the nozzle brush + screw/nut on the Nozzle Brush Mount, velcro/zip ties, and a buffer for the external Dragon Burner Toolhead/StealthChanger backplate assembly hardware (not detailed in this repo's BOM).

Approximate filament weight for the printed parts weighed so far (not cost - filament price varies by brand/color, budget separately):

| Part | Weight | Qty | Total |
|---|---|-----|---|
| [Toolhead Dock](dock/) (per dock) | 54g | 6 | 324g |
| [Dragon Burner Toolhead](dragon-burner-toolhead/) (cowl + EBB36 cover, per toolhead) | 75g | 6 | 450g |
| [CAN Distribution Board Mount](can-distribution-board-mount/) | 18g | 1 | 18g |
| [Umbilical Backplate](umbilical-backplate/) | 63g | 1 | 63g |
| [Spool Holder](spool-holder/) end caps | 32g | 2 | 64g |
| [Spool Holder](spool-holder/) roller dividers | 22g | 5 | 110g |

**Known filament total: ~1029g (~1.03kg)** for this 6-toolhead build - **~129g of that scales per toolhead** (54g dock + 75g cowl/EBB36 cover); if you're building a different toolhead count, multiply that 129g by your count instead of 6 and add the fixed ~255g (CAN distribution mount, backplate, spool holder parts). Not yet weighed: [Umbilical Bracket](umbilical-bracket/), Spool Holder tube guides/ports, and [Nozzle Brush Mount](nozzle-brush-mount/) - add those plus a buffer for failed prints/waste to get your real total.

All parts are printed in ABS or ASA (needed for heat resistance near the toolhead/hotend), at a ballpark $20 per 1kg spool.

| Color strategy | Spools needed | Est. Cost |
|---|---|---|
| 1-2 colors (shared spools) | 1-2 | **~$20-40** |
| 6 unique colors, one per toolhead | up to 6 | ~$120 |

Most vendors only sell full 1kg spools, so unique-per-toolhead colors mean buying up to 6 spools even though each only uses a fraction - the ~$20 base price above assumes you're fine consolidating colors.

You can reference [BOM.csv](BOM.csv) and the individual component READMEs for full parts lists and source links, and swap in your own pricing for anything marked as a rough estimate or covered by the misc hardware estimate above.

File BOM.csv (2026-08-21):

Assembly | Type | Part | Quantity | Source | Unit Price | Total Price | Alt Source | Note
dock | print | toolhead-dock-base.STL | 1
dock | print | toolhead-dock-plate.STL | 1
dock | print | toolhead-dock-bracket.STL | 1
dock | print | toolhead-dock-brush-holder.STL | 1
dock | print | Toolhead-dock-nozzle-pad-clip.STL | 1
dock | buy | Silicone Nozzle Brush (Bambu Lab A1 Mini size cut in half) | 1 | https://s.click.aliexpress.com/e/_c2wvhLBd | 0.15 | 0.15 | https://amzn.to/4zvQkCc | Same brush type as Nozzle Brush Mount, cut in half; $2.96 per 10pcs, enough for the whole build + extras
dock | buy | 16mm M5 Button Head Cap Screw | 4 |  |  |  |  | Covered by overall misc hardware estimate see main README
dock | buy | 10mm M5 Button Head Cap Screw | 1 |  |  |  |  | Covered by overall misc hardware estimate see main README
dock | buy | 14mm M3 Button Head Cap Screw | 2 |  |  |  |  | Covered by overall misc hardware estimate see main README
dock | buy | M5 Heatset Insert 7mm D x 5mm L | 4 |  |  |  |  | Covered by overall misc hardware estimate see main README
dock | buy | 8mm M3 Button Head Cap Screw | 2 |  |  |  |  | Covered by overall misc hardware estimate see main README
dock | buy | M3 Heatset Insert 5mm D x 4mm L | 2 |  |  |  |  | Covered by overall misc hardware estimate see main README
nozzle-brush-mount | print | nozzle-brush-mount-base.STL | 1
nozzle-brush-mount | print | nozzle-brush-mount-top.STL | 1
nozzle-brush-mount | buy | Silicone Nozzle Brush (for Bambu Lab A1/A1 MINI) | 1 |  |  |  |  | Covered by overall misc hardware estimate see main README
nozzle-brush-mount | buy | 20mm M3 Socket Head Cap Screw | 1 |  |  |  |  | Covered by overall misc hardware estimate see main README
nozzle-brush-mount | buy | M3 2020 Roll Nut | 1 |  |  |  |  | Covered by overall misc hardware estimate see main README
nozzle-brush-mount | reference | Sexball Probe Assembly | 1 | https://github.com/DraftShift/StealthChanger/wiki/Bill-of-Materials#sexball-probe |  |  |  | Upstream project - see project for parts and sourcing
nozzle-brush-mount | buy | Mellow Hartk Sexbolt Z Limit Endstop | 1 | https://s.click.aliexpress.com/e/_c2vVlF4R | 10.9 | 10.9 | https://amzn.to/4bZMur3 | Sexball probe part
nozzle-brush-mount | buy | M5 30mm Stainless Steel Outside Thread Solid Dowel Pin | 5 | https://s.click.aliexpress.com/e/_c3g0o8ox | 0.63 | 3.14 | https://amzn.to/4zzrLEI | Sexball probe part; pack of 5
nozzle-brush-mount | buy | 12.7 or 12mm D M5 Stainless Steel Drilling Balls Female Thread | 1 | https://s.click.aliexpress.com/e/_c2wXXZR9 | 6.64 | 6.64 | https://amzn.to/46cNQv5 | Sexball probe part
spool-holder | print | spool-holder-roller-end.STL | 2
spool-holder | print | spool-holder-roller-divider.STL | 5
spool-holder | print | spool-holder-tube-guide.STL | 6
spool-holder | print | spool-holder-port.STL | 2
spool-holder | buy | 2020 Extrusion, 420mm Length | 4 | https://amzn.to/4hoHVKv |  | 49.99 | https://amzn.to/4gHHdXQ | Cut from a 10pc pack of 500mm bars, only sold as a full pack; per-piece cost not separable
spool-holder | buy | 2020 Extrusion, 260mm Length | 4 | https://amzn.to/4hoHVKv |  |  | https://amzn.to/4gHHdXQ | Cut from the same pack (pairs with a 240mm piece per bar), cost counted on the 420mm line
spool-holder | buy | 2020 Extrusion, 240mm Length | 4 | https://amzn.to/4hoHVKv |  |  | https://amzn.to/4gHHdXQ | Cut from the same pack (pairs with a 260mm piece per bar), cost counted on the 420mm line
spool-holder | buy | M5 10mm Button Head Cap Screw | 16 | https://amzn.to/4hoHVKv |  |  |  | Covered by overall misc hardware estimate see main README
spool-holder | buy | 8mmx460mm Rod (Smooth or Threaded) | 2 | https://s.click.aliexpress.com/e/_c4NcuZcf | 5.1 | 10.1 | https://amzn.to/4g3PELE | Sourced as 2pc pack of 8mm x 500mm linear rod, cut to length
spool-holder | buy | 608 Bearings (base) | 4 | https://amzn.to/4cwubtG | 0.27 | 1.07 | https://s.click.aliexpress.com/e/_c3qePSft | $5.36 per 20-pack, 4 not tied to a toolhead
spool-holder | buy | 608 Bearings (per toolhead x6) | 48 | https://amzn.to/4cwubtG | 0.27 | 12.86 | https://s.click.aliexpress.com/e/_c3qePSft | $5.36 per 20-pack, 8 per toolhead x6
spool-holder | buy | ECAS04 Quick Connect Collet | 12 | https://www.aliexpress.us/item/3256812555226121.html | 0.25 | 3 | https://amzn.to/4gs7Q1K | 2 per toolhead x6
spool-holder | buy | PTFE Tube Clear 4mmOD x 3mm ID (~26in) spool holder to umbilical plate | 6 | https://s.click.aliexpress.com/e/_c3qePSft | 1.27 | 7.63 | https://amzn.to/4gMqQIz | $1.93/meter, 1 per toolhead x6
spool-holder | buy | PTFE Tube Clear 4mmOD x 3mm ID (~10in) internal guide | 6 | https://s.click.aliexpress.com/e/_c3qePSft | 0.49 | 2.94 | https://amzn.to/4gMqQIz | $1.93/meter, 1 per toolhead x6
spool-holder | buy | M3 Heatset Insert 5mm D x 4mm L | 4 |  |  |  |  | Covered by overall misc hardware estimate see main README
spool-holder | buy | M3 12mm Socket Head Cap Screw | 4 |  |  |  |  | Covered by overall misc hardware estimate see main README
spool-holder | buy | M3 10mm Socket Head Cap Screw | 4 |  |  |  |  | Covered by overall misc hardware estimate see main README
spool-holder | buy | M3 2020 Roll Nut | 4 |  |  |  |  | Covered by overall misc hardware estimate see main README
umbilical-backplate | print | umbilical-backplate.STL | 1
umbilical-backplate | print | umbilical-backplate-nut-retainer.STL | 1
umbilical-backplate | buy | ECAS04 quick connect collet | 12 | https://www.aliexpress.us/item/3256812555226121.html | 0.25 | 3 | https://amzn.to/4gs7Q1K
umbilical-backplate | buy | GX12-4 Jack | 6 | https://s.click.aliexpress.com/e/_c2vhMl6x | 0.59 | 3.54 | https://amzn.to/4gaFnOZ | Price per male/female pair (includes mating GX12-4 Plug), 1 pair per toolhead x6
umbilical-backplate | buy | M3 Heatset Insert 5mm D x 4mm L | 6 |  |  |  |  | Covered by overall misc hardware estimate see main README
umbilical-backplate | buy | M3x10mm screw or M3 set screw | 6 |  |  |  |  | Covered by overall misc hardware estimate see main README
umbilical-backplate | buy | M5 10mm Button Head Cap Screw | 3 |  |  |  |  | Covered by overall misc hardware estimate see main README
umbilical-backplate | buy | M5 2020 Roll Nut | 3 |  |  |  |  | Covered by overall misc hardware estimate see main README
umbilical-bracket | print | umbilical-bracket-bottom.STL | 1
umbilical-bracket | print | umbilical-bracket-top.STL | 1
umbilical-bracket | buy | M3 6mm Thread Rolling Screw | 1 |  |  |  |  | Covered by overall misc hardware estimate see main README
umbilical-assembly | assembly | umbilical-bracket | 8
umbilical-assembly | buy | CAN Bus Cable 4mm diameter (~23.5in, 600mm) | 1 |  | 4 | 4 |  | Cut from a 6ft 100W shielded USB-C cable (2 CAN cables per cable); exact cable no longer sold. Verify replacement cable rating meets your toolhead electronics requirements; alternatives: 240W USB-C cable, chainflex cable
umbilical-assembly | buy | 4mmOD x 3mm ID PTFE Guide Tube (~26in, 660mm) | 1 | https://s.click.aliexpress.com/e/_c3qePSft | 1.27 | 1.27 | https://amzn.to/4gMqQIz | $1.93/meter
umbilical-assembly | buy | GX12-4 Plug | 1 | https://s.click.aliexpress.com/e/_c2vhMl6x |  |  | https://amzn.to/4gaFnOZ | Priced with the mating GX12-4 Jack see Umbilical Backplate BOM
umbilical-assembly | buy | 2x2 Microfit Connector | 1 | https://amzn.to/4ifp2tK |  |  |  | Comes with the EBB36 toolboard not purchased separately
umbilical-assembly | buy | .3mmx3mm flat coil spring (70mm) | 1 | https://amzn.to/4wyCufH | 1.67 | 13.39 | https://s.click.aliexpress.com/e/_c2xB7uAf | Cut from a 0.3x3x34x1900mm roll ($11.00 total, ~$1.67/umbilical), one roll covers the whole build (8 umbilicals)
umbilical-assembly | buy | .3mmx3mm flat coil spring (100mm) | 1 | https://amzn.to/4wyCufH |  |  | https://s.click.aliexpress.com/e/_c2xB7uAf | Cut from the same roll cost counted on the 70mm line
dragon-burner-toolhead | reference | Dragon Burner Toolhead (chirpy2605) | 1 | https://github.com/chirpy2605/voron-user-mods/tree/main/Universal/DragonBurner |  |  |  | Upstream project - base toolhead body printed parts and hardware; external assembly hardware covered by overall misc hardware estimate. see main README
dragon-burner-toolhead | reference | StealthChanger DragonBurner Backplate | 1 | https://stealthchanger.com/hardware/guides/backplates/4_dragonburner/#printed-bom |  |  |  | Upstream project - printed backplate mounting to the StealthChanger toolchanger
dragon-burner-toolhead | buy | 4x12mm M3 Dowel Pin | 3 | https://s.click.aliexpress.com/e/_c3iT67xV | 0.75 | 2.25 | https://amzn.to/4gjgK1h | Sold in packs of 10; secures the StealthChanger backplate
dragon-burner-toolhead | buy | TZ V6 2.0 Hotend | 1 | https://s.click.aliexpress.com/e/_c3Mq5ohd | 17.87 | 17.87 | https://amzn.to/4wB6uYB
dragon-burner-toolhead | buy | Moons Nema14 Motor | 1 | https://s.click.aliexpress.com/e/_c3PY8IAP | 19.84 | 19.84 | https://amzn.to/4wGdByK
dragon-burner-toolhead | buy | BIGTREETECH EBB36 CANBus Toolhead Board V1.2 | 1 | https://s.click.aliexpress.com/e/_c3MC48Xt | 15.39 | 15.39
dragon-burner-toolhead | buy | Voron Tap Probe Kit | 1 | https://s.click.aliexpress.com/e/_c3SsvTCX | 9.19 | 9.19 | https://amzn.to/4goA2T5
dragon-burner-toolhead | buy | Gdstime 3010 24V Sleeve 2P2.54 Fan | 1 | https://s.click.aliexpress.com/e/_c3NtUlNp | 4.08 | 4.08 | https://amzn.to/4wLNCWN
dragon-burner-toolhead | buy | Gdstime 4010 24V H Blower 2P2.54 Fan | 2 | https://s.click.aliexpress.com/e/_c4E8RYo3 | 5.14 | 10.28 | https://amzn.to/45YBXcp
dragon-burner-toolhead | reference | Sherpa Mini Extruder (Annex Engineering) | 1 | https://github.com/Annex-Engineering/Sherpa_Mini-Extruder |  |  |  | Upstream project - extruder selection used with this build see project for full BOM
dragon-burner-toolhead | buy | Sherpa Mini Hardware Kit (bearings/pins/springs) | 1 | https://s.click.aliexpress.com/e/_c4qK86KB | 4.08 | 4.08 | https://amzn.to/3Sp1WWZ | Self-printed Sherpa Mini; cheap AliExpress hardware kit estimate
dragon-burner-toolhead | print | dragonburner-cowl.STL | 1
dragon-burner-toolhead | buy | 35mm M3 Socket Head Cap Screws | 2 | https://s.click.aliexpress.com/e/_c3tmFYGL | 0.23 | 2.25 | https://amzn.to/4xbUg9I | $2.25 per 10pc pack, only sold as a full pack
dragon-burner-toolhead | print | ebb36-strain-relief-cover.STL | 1
dragon-burner-toolhead | buy | M3 12mm Standoff (Male-Female) | 2 |  |  |  |  | Covered by overall misc hardware estimate see main README
dragon-burner-toolhead | buy | M3 18mm Standoff (Female-Female) | 2 |  |  |  |  | Covered by overall misc hardware estimate see main README
dragon-burner-toolhead | buy | M3 Heatset Insert 5mm D x 4mm L | 1 |  |  |  |  | Same insert used elsewhere in this project; covered by overall misc hardware estimate see main README
dragon-burner-toolhead | buy | M3 20mm Button Head Cap Screw | 2 |  |  |  |  | Covered by overall misc hardware estimate see main README
dragon-burner-toolhead | buy | M3 8mm Socket Head Cap Screw | 2 |  |  |  |  | Covered by overall misc hardware estimate see main README
dragon-burner-toolhead | buy | Velcro or Zip Tie | 1 |  |  |  |  | Secures the strain relief connection; covered by overall misc hardware estimate see main README
can-distribution-board-mount | print | can-distribution-board-mount.STL | 1 |  |  |  |  | Files coming soon
can-distribution-board-mount | buy | FYSETC CAN Bus Distribution Board for StealthChanger | 1 | https://www.fabreeko.com/products/can-bus-distribution-board-for-stealth-changer-by-fysetc | 19.99 | 19.99 |  | 6-channel switched CAN/power distribution
can-distribution-board-mount | buy | M3 8mm Thread Rolling Screw | 4 |  |  |  |  | Mounts the distribution board to the mount; covered by overall misc hardware estimate see main README
can-distribution-board-mount | buy | M3 10mm Socket Head Cap Screw | 2 |  |  |  |  | Attaches the mount to the Umbilical Backplate; covered by overall misc hardware estimate see main README
can-distribution-board-mount | reference | BTT U2C CAN Bridge | 1 | https://amzn.to/45Fp9Hz | 19.99 | 19.99 | https://s.click.aliexpress.com/e/_c3FzcP0n | Suggested pairing (host-side USB-to-CAN adapter) not part of this mount enclosure
filament | buy | Polymaker ASA Pop Blue (Cyan) | 1 | https://amzn.to/4gcIvKo |  |  |  | ASA only; see main README for full filament color list
filament | buy | MatterHackers Magenta ABS | 1 | https://www.matterhackers.com/store/3d-printer-filament/magenta-abs-filament-1.75mm |  |  |  | ABS only; see main README for full filament color list
filament | buy | MatterHackers Yellow ABS | 1 | https://www.matterhackers.com/store/l/175mm-abs-filament-yellow-1-kg/sk/M-1NX-QXFR |  |  |  | ABS only; see main README for full filament color list
filament | buy | Polymaker White (ABS or ASA - pick one) | 1 | https://amzn.to/4cA1c8l |  |  | https://amzn.to/45FyLlC | ASA alternative; See main README for full filament color list
filament | buy | Polymaker Gray (ABS or ASA - pick one) | 1 | https://amzn.to/4xRpfb5 |  |  | https://amzn.to/3ULpFkU | ASA alternative; See main README for full filament color list
filament | buy | Polymaker Black (ABS or ASA - pick one) | 1 | https://amzn.to/4zvPRzW |  |  | https://amzn.to/4xUeXqN | ASA alternative; See main README for full filament color list

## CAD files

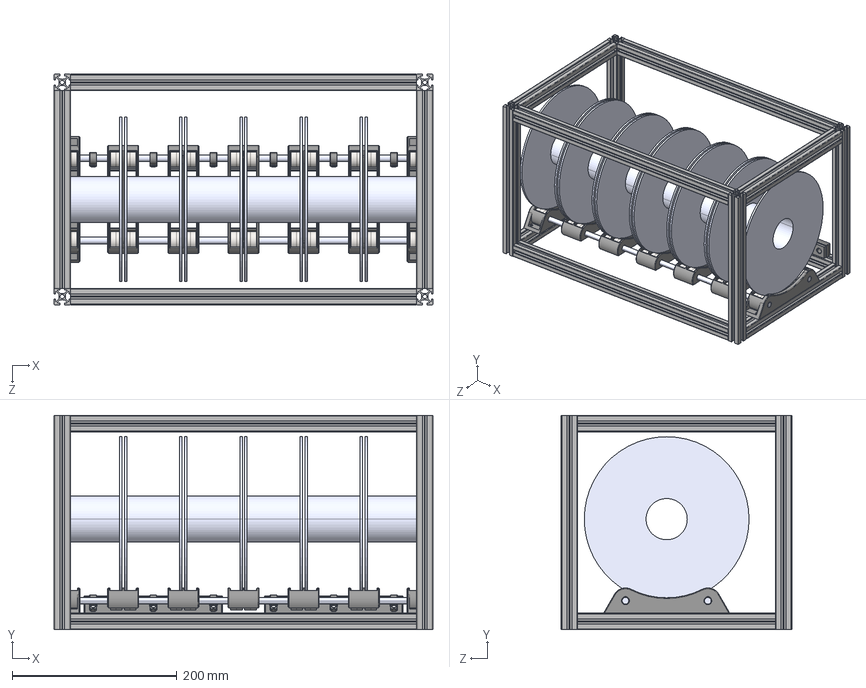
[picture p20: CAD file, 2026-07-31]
spool-holder/spool-holder-assembly.STEP
460.0 x 260.0 x 280.0 mm
Filament Spool x 6
8mmx460mm rod x 2
2020 Extrusion_420 x 4
2020 Extrusion_240 x 4
2020 Extrusion_260 x 4
Spool Divider x 5
608 Ball Bearing - Nelson x 84
Spool Divider_End Bracket x 2
Spool Holder Filament Ports x 2
Underspool filament Guide x 6

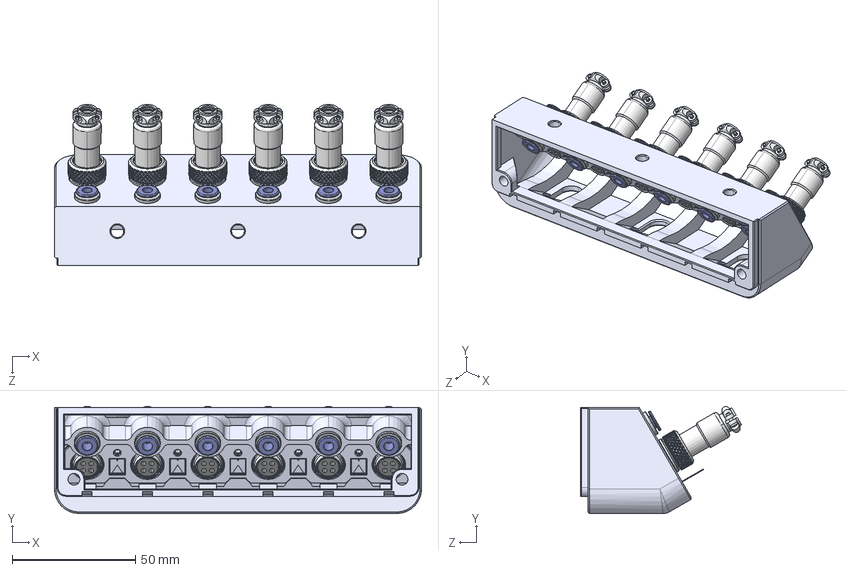
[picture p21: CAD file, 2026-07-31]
umbilical-backplate/umbilical-backplate-assembly.STEP
149.0 x 43.4 x 65.4 mm
CAN Umbilical Mount 6x - ECAS04 - broekn refs
Jack Body x 6
Jack Nut x 6
Jack Insert x 6
Jack O-ring x 6
ecas04 x 12
Part30^Umbilical Plug Subassembly ECAS04 x 6

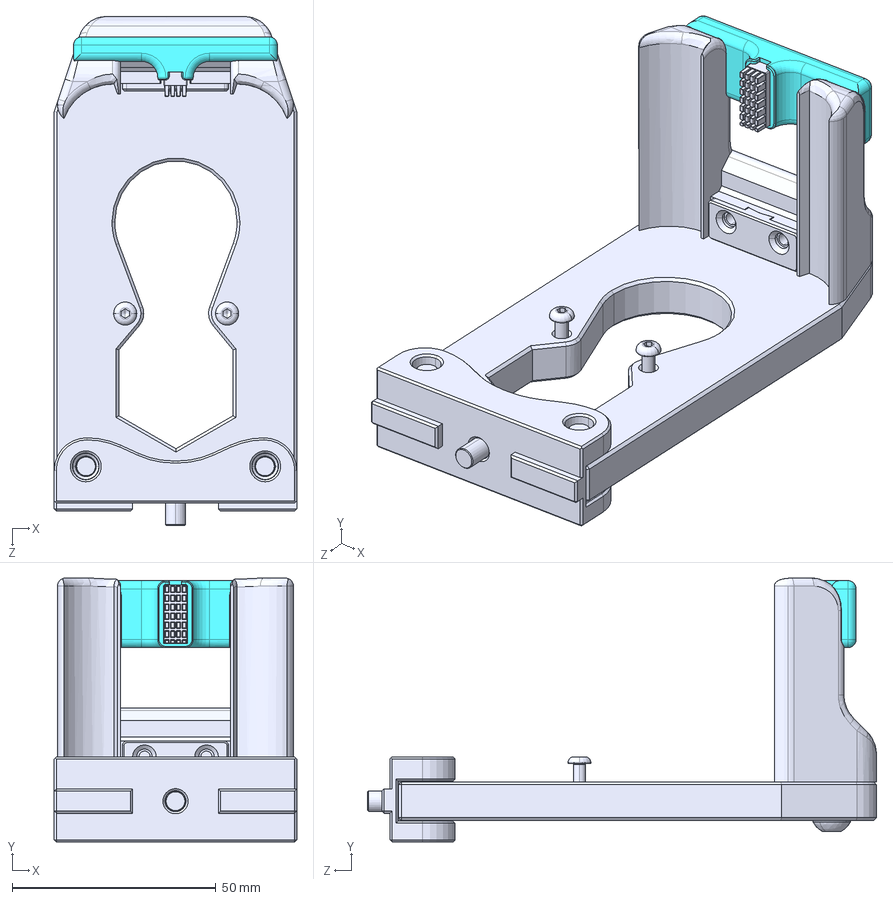
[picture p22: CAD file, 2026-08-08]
dock/toolhead-dock-assembly.STEP
59.5 x 64.8 x 124.9 mm
Acrylic Dock Plate
Acrylic Dock Printed Bracket
Acrylic Dock Pinted Base
M5 BHCS_10mm
M5 BHCS_16mm x 4
Nozzel Pad Clip Curved
M3x14 BHCS x 2
Dock Brush Holder Bottom Curve
Silicone Nozzle Cleaning Brush_Half Brush

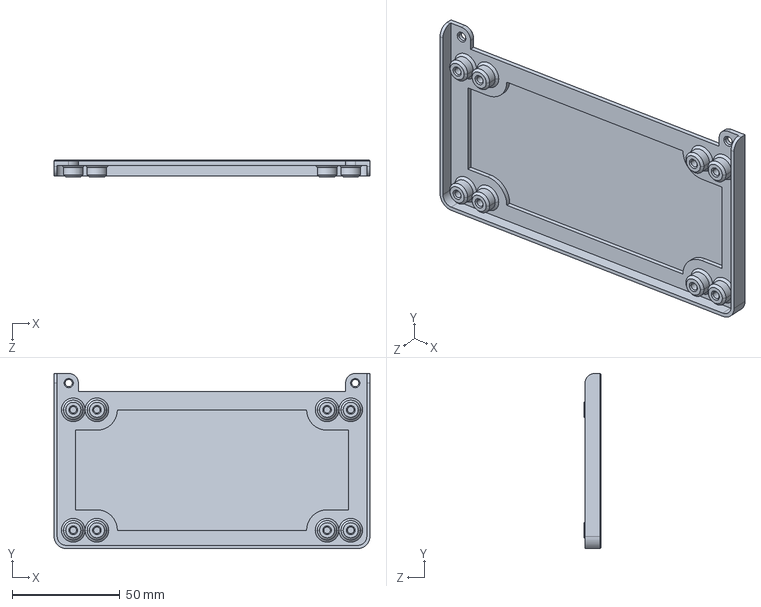
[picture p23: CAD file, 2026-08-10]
can-distribution-board-mount/can-distribution-board-mount.STEP
146.9 x 81.4 x 8.00 mm

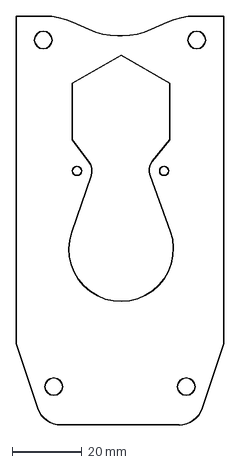
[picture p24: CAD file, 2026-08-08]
dock/laser-cut-files/toolhead-dock-plate-1tool.DXF
59.5 x 117.3 mm

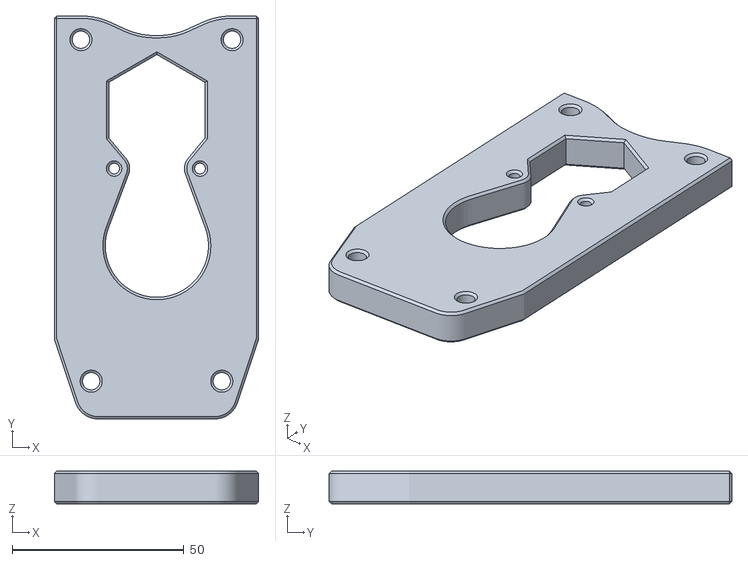
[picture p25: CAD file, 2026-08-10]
dock/toolhead-dock-plate.STL
59.5 x 117.3 x 9.50

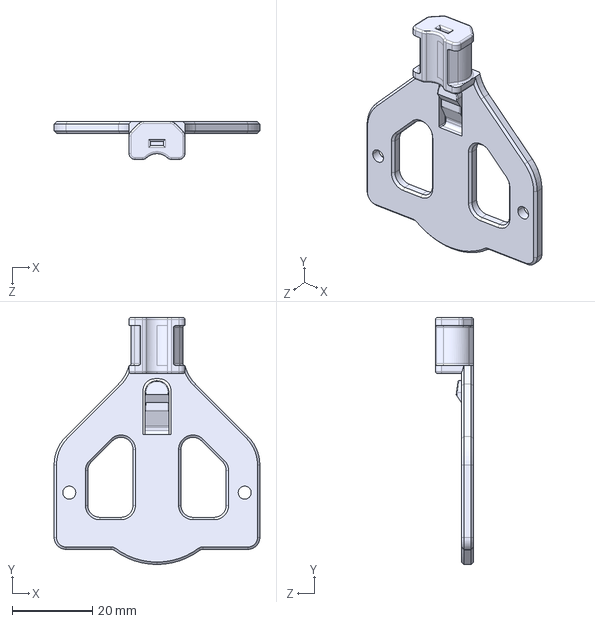
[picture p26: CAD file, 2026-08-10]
dragon-burner-toolhead/ebb36-strain-relief-cover.STEP
51.4 x 61.7 x 9.50 mm

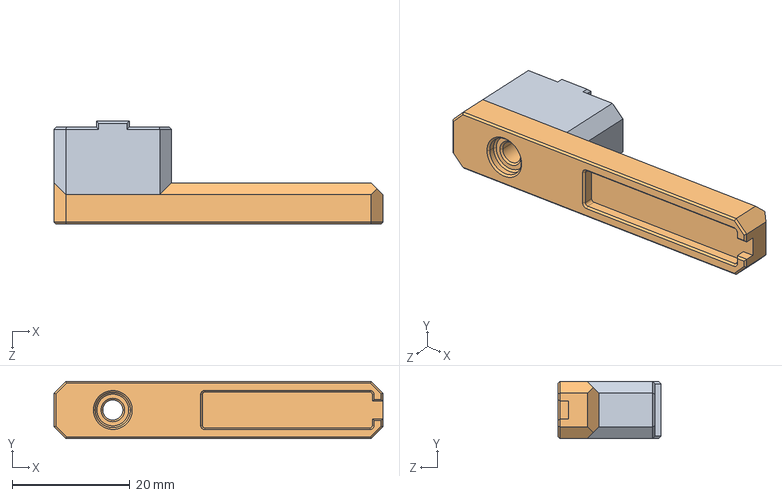
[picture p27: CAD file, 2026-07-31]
nozzle-brush-mount/nozzle-brush-mount.STEP
55.9 x 9.70 x 17.5 mm

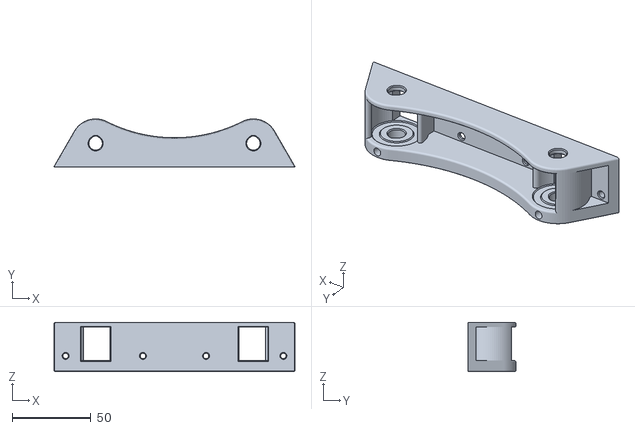
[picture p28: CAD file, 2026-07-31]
spool-holder/spool-holder-roller-end.STL
152.8 x 30.5 x 31.3

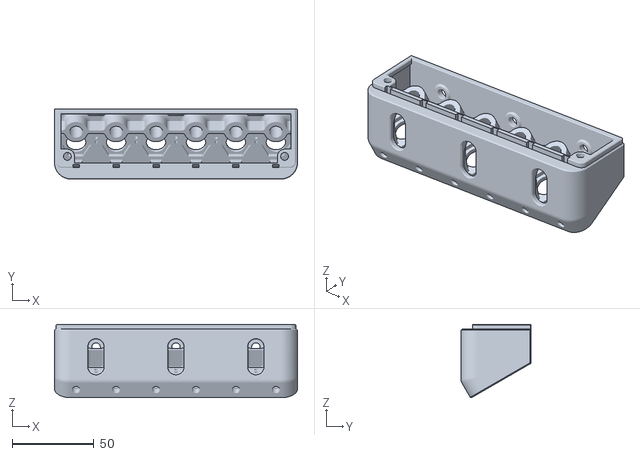
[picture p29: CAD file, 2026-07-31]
umbilical-backplate/umbilical-backplate.STL
149.0 x 43.0 x 45.0

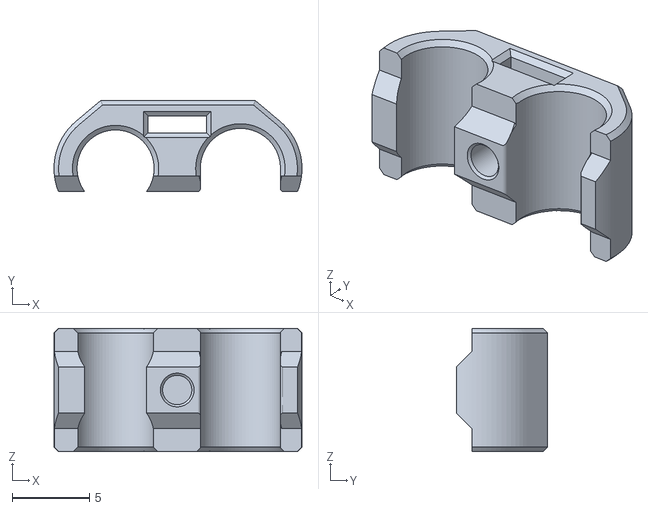
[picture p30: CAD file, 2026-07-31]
umbilical-bracket/umbilical-bracket-bottom.STL
16.1 x 5.91 x 8.00

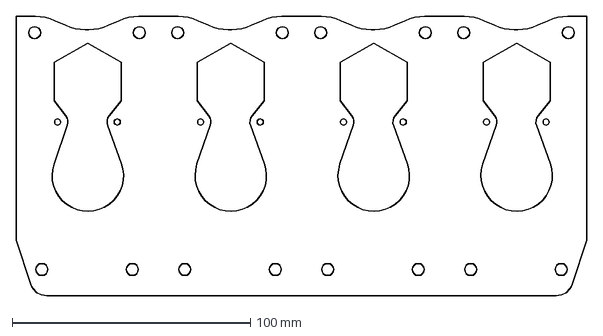
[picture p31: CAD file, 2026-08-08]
dock/laser-cut-files/toolhead-dock-plate-4tool.DXF
239.5 x 117.3 mm

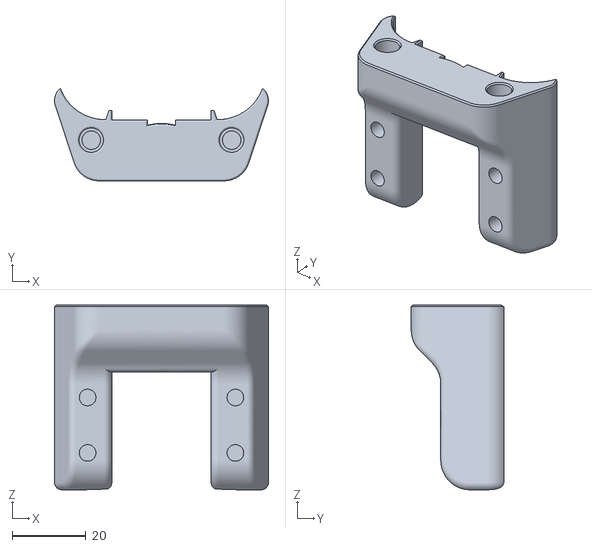
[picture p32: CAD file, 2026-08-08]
dock/toolhead-dock-base.STL
57.9 x 25.1 x 50.0

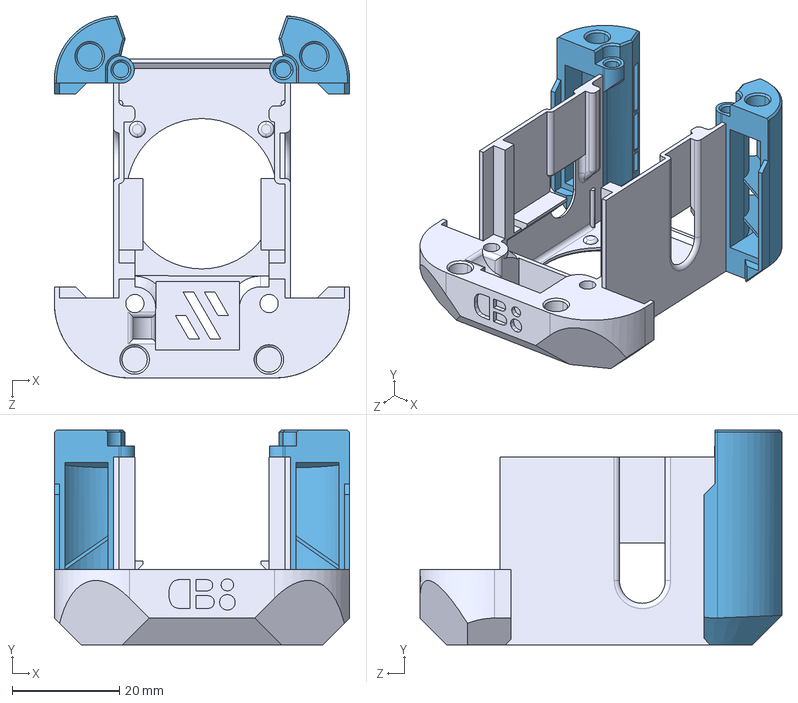
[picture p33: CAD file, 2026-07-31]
dragon-burner-toolhead/dragon-burner-cowl.STEP
55.0 x 40.0 x 67.4 mm
Standard (1)
Standard
MainBody-tapchanger

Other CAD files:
nozzle-brush-mount/nozzle-brush-mount-base.STL
umbilical-bracket/umbilical-bracket.STEP
dock/laser-cut-files/toolhead-dock-plate-3tool.DXF
nozzle-brush-mount/nozzle-brush-mount-top.STL
can-distribution-board-mount/can-distribution-board-mount.STL
dock/laser-cut-files/toolhead-dock-plate-2tool.DXF
dock/laser-cut-files/toolhead-dock-plate-5tool.DXF
dock/laser-cut-files/toolhead-dock-plate-6tool.DXF
dock/toolhead-dock-bracket.STL
dock/toolhead-dock-brush-holder.STL
dock/toolhead-dock-nozzle-pad-clip.STL
dragon-burner-toolhead/dragon-burner-cowl.STL
dragon-burner-toolhead/ebb36-strain-relief-cover.STL
spool-holder/spool-holder-port.STL
spool-holder/spool-holder-roller-divider.STL
spool-holder/spool-holder-tube-guide.STL
umbilical-backplate/umbilical-backplate-nut-retainer.STL
umbilical-bracket/umbilical-bracket-top.STL

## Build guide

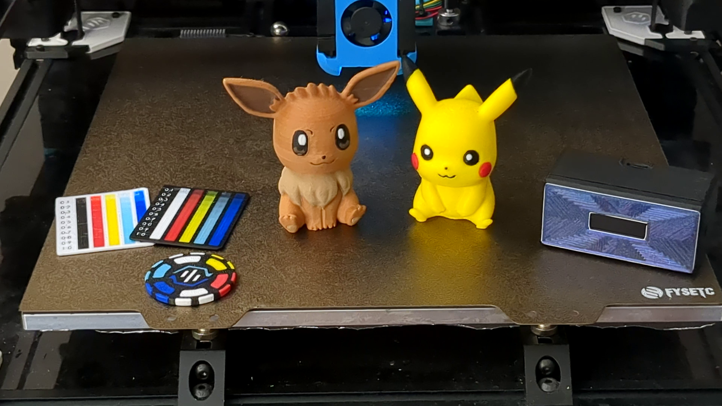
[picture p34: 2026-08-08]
images/finished-prints.png

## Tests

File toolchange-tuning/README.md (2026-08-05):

# Toolchange Tuning

Parameters and dock path tuned to reduce toolchange time while maintaining reliability. Changes were made to both `printer.cfg` (motion limits) and the StealthChanger macro configs. Overall this reduced the toolchange time from 11.57s to 4.8s, on a standard 25V motor setup. 

## Tuned Parameters

| Parameter | File | Default | Tuned | Notes |
|---|---|---|---|---|
| `max_velocity` | `printer.cfg` | 300 mm/s | **500 mm/s** | Speed up fast travel mostly when approaching or traveling between docks |
| `max_z_velocity` | `printer.cfg` | 100 mm/s | **200 mm/s** | Faster Z going up and down from the docks |
| `max_z_accel` | `printer.cfg` | 1000 mm/s² | **1500 mm/s²** | Faster Z acceleration |
| `params_safe_y` | `macros.cfg` | 120 mm | **80 mm** | Y clearance closer to the dock |
| `params_close_y` | `macros.cfg` | 15 mm | **10 mm** | Keeps shuttle closers to tools between dropoff and pickup |
| `params_path_speed` | `macros.cfg` | 900 mm/min (15 mm/s) | **6000 mm/min (100 mm/s)** | Much faster speed during the pickup and and drop off |
| `params_sc_path` | `Toolhead_T*.cfg` | 6 waypoints | **4 waypoints** | Removed ramped approach for a straight line |

## Dock Path Detail (`params_sc_path`)

All tools use `params_type: 'sc'`. The original 6-waypoint path had an angled ramp in, siultaneous Y/Z move, when docking and undocking. The shuttle now approaches the dock directly in a pure linear Y axis movement, then pure Z move to engage/disengage to toolhead.

**Before (6 waypoints):**
```python
[{'y':9.5, 'z':7}, {'y':9.5, 'z':2}, {'y':5.5, 'z':0}, {'z':0, 'y':0, 'f':0.5}, {'z':-11.5, 'y':0}, {'z':-11.5, 'y':10}]
```

**After (4 waypoints):**
```python
[{'y':5.5, 'z':0}, {'z':0, 'y':0, 'f':0.5}, {'z':-11.5, 'y':0}, {'z':-11.5, 'y':10}]
```

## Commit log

2026-07-31 Added draggon burner full assembly step file
2026-08-08 Added laser cut vector files for the dock plates, and made a minor edit to the dock base so that is fits more common M5 heat set inserts.
    [toolhead-dock-assembly.STEP, toolhead-dock-base.STL, toolhead-dock-plate-1tool.DXF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]
2026-08-08 Updated laser cut file readme
2026-08-08 Added sources for toolhead parts
    [BOM.csv]
2026-08-10 Added Ebb36 strain relief cover
    [BOM.csv, dragonburner-cowl.STEP, dragonburner-cowl.STL]
2026-08-10 Updated with ebb26 strain relief cover files and renamed toolhead folder
    [dragon-burner-cowl.STEP, dragon-burner-cowl.STL, ebb36-strain-relief-cover.STEP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]
2026-08-10 Reorganized parts list for Toolhead
    [BOM.csv]
2026-08-10 Updated nozzle brush readme
    [BOM.csv]
2026-08-10 Added cost estimates
    [BOM.csv, can-distribution-board-mount.STEP, can-distribution-board-mount.STL]
2026-08-10 Fixed Dock Plate STL, added note for print settings
    [toolhead-dock-plate.STL]
2026-08-10 moved print note
2026-08-21 Added alt source links and update some pricing
    [BOM.csv]
2026-08-21 Updated link to Dragonburner toolhead project.
